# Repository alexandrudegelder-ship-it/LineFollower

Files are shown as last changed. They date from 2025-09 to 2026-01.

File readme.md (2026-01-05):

# LineFollower the best one yet !

Are you here to build a line follower ? Do you think you got what it takes to break the speed record of 0.97 m/s ? Then you have come to the right one ! 
* **Disclaimer 1: Make sure that you have enough funding, since the costs including the delivery charges of building this linefollower can be expensive in JLCPCB and Aliexpress. The calculations that I have done in the bills of materials are for the students that DON'T HAVE ANY components AT ALL. Best way to lower the costs is by forming a group of 5 people, so each of the students can have a linefollower. Also, I bought most of the components at a time when there were good deals. If possible, buy in bulk for components you buy on Aliexpress.**

* **Disclaimer 2: Please note that my electrical schematics still contain various errors. I intentionally left the errors in the documentation to ensure that working on this project isn't just a simple matter of copy-pasting. You really need to think critically about what you are doing. So, if you're planning to replicate this, I want to warn you: be careful, because 'there is more than meets the eye.'. 😜**

# Mijn Robot Project

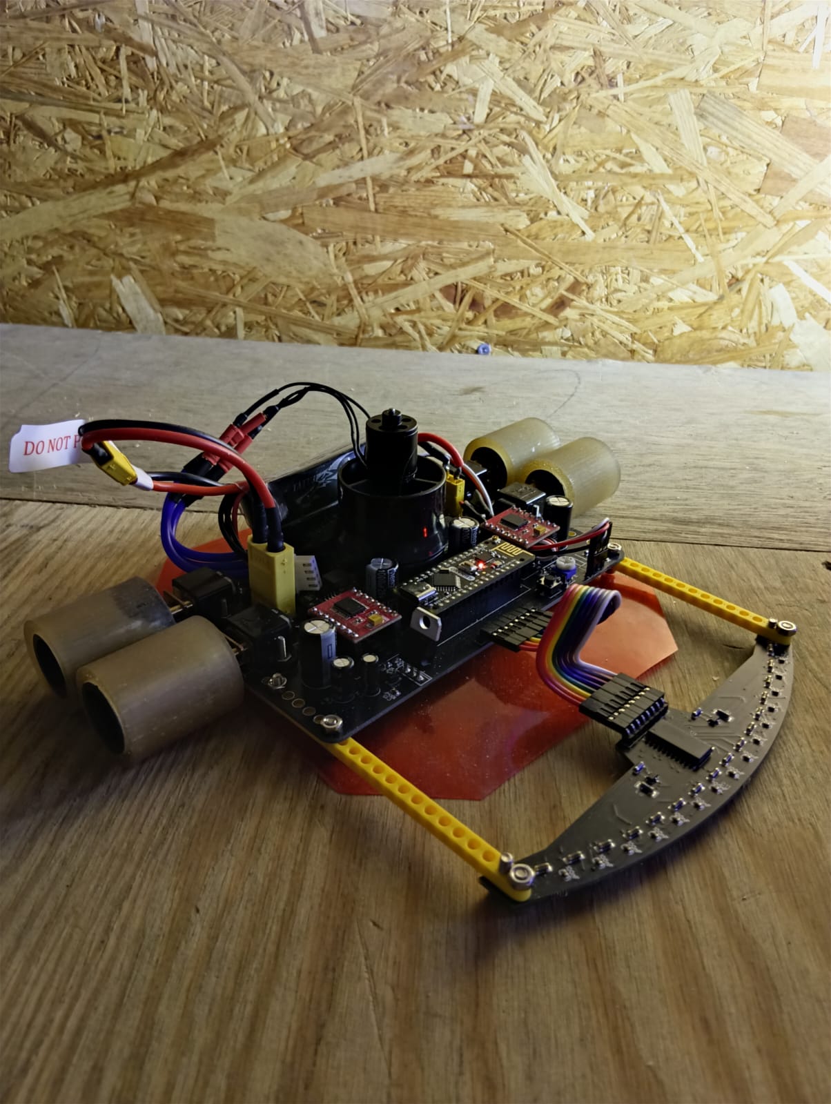
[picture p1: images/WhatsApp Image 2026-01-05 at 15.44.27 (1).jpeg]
De afgebouwde robot


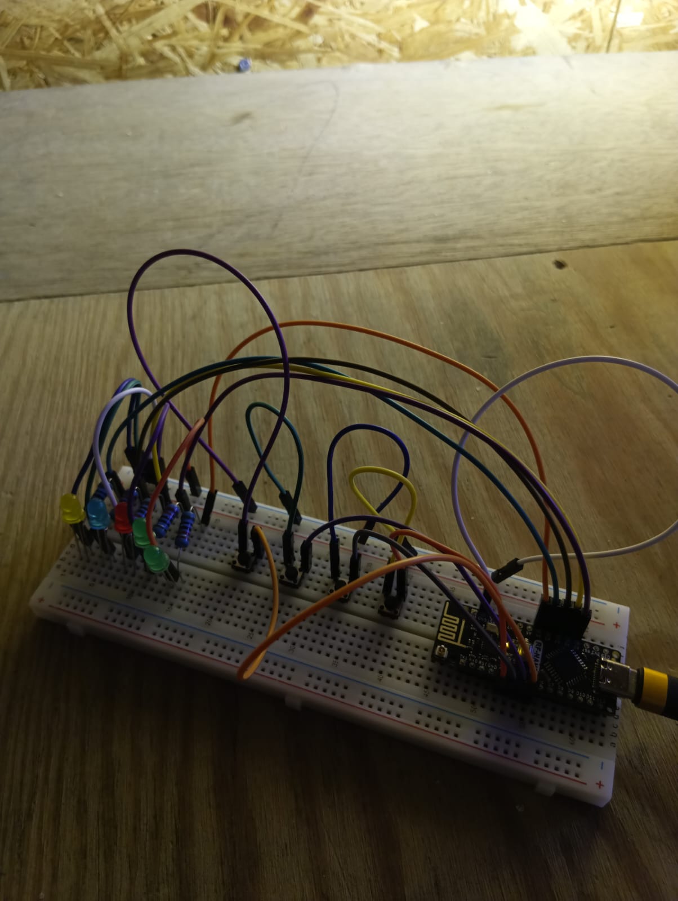
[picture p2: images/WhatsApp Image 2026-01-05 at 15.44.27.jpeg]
Breadboard testopstelling


## Specifications

* **Microcontroller:** 2x Arduino RF-Nano V3.0
* **Motors:** 2 (4x) motors GA12-N20 Motor 6V 2000 RPM (1:10)
* **H-bridge:** 2x TB6612FNG
* **Sensors:** 16x QRE1113 (Line sensor array)
* **Batteries:** 11.1V 450 mAh 3S 75C 5Wh battery
* **Wireless communication:** RF (Built-in RF in Arduino Nano)
* **Weight:** with the battery of the teacher 0.401 kg, with the one given in de BOM template 0.312 kg 
* **Speed:** Highest possible speed depending on the course (~ 0.91m/s)
* **Disclaimer:** This is currently the highest speed yet without the ventilator and POT value is 160. Further testing is needed which I have not been able to do so because of shortage of time.

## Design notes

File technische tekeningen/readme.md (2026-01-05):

# PCB ontwerp: Lineaire sensor en PCB board linefollower

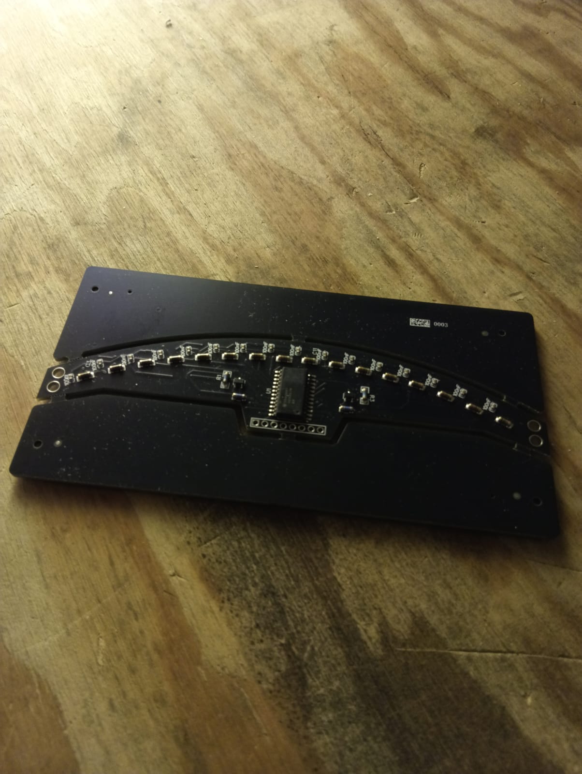
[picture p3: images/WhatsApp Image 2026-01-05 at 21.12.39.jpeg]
PCB ontwerp Lineaire sensor


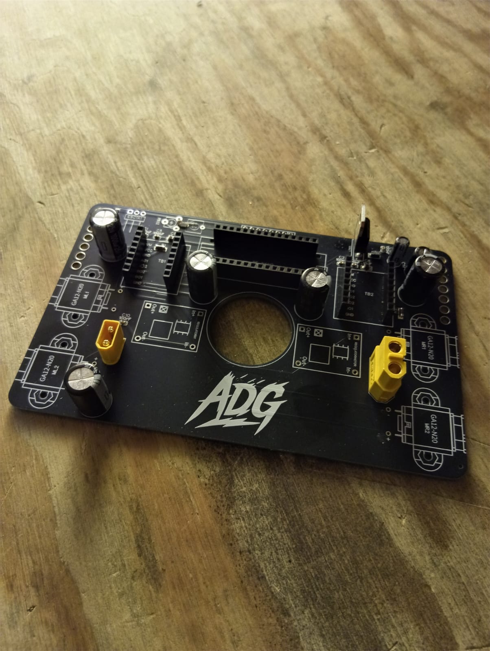
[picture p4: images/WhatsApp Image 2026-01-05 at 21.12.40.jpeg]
PCB board linefollower


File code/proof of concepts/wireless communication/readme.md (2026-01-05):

# draadloze communicatie proof of concept

# Technische Analyse: Arduino RF Nano V3.0 & Communicatie-architectuur

De **Arduino RF Nano V3.0** is een hybride microcontroller die een ATmega328P (de klassieke Nano) integreert met een **nRF24L01+** 2.4GHz transceiver op één enkele PCB. Deze integratie vereist een slimme toewijzing van pinnen om conflicten tussen interne radiofuncties en externe datacommunicatie te voorkomen.

## 1. Interne Radio-interface (SPI)

De interne nRF24L01+ chip communiceert met de processor via de **SPI-bus**. In het ontwerp van de RF Nano zijn de volgende pinnen intern vast verbonden (hard-wired):

* **D9 (CSN) & D10 (CE):** Deze pinnen sturen de radiochip aan.
* **D11, D12, D13:** De standaard SPI-lijnen (MOSI, MISO, SCK).

Omdat deze pinnen essentieel zijn voor de draadloze werking, mogen ze niet voor andere kritieke taken in het schema worden gebruikt.

## 2. Externe Communicatie via D7 en D8

Voor de bedrade communicatie tussen de bedieningsunit en de sensormodule is er specifiek gekozen voor pinnen **D7** en **D8**.

### Waarom D7 en D8?

In jouw gecorrigeerde schema fungeren deze pinnen als een **dedicated communicatiebus**.

1. **Isolatie van de Radio:** Door D7 en D8 te gebruiken, blijft de interne radio (op D9/D10) volledig ongestoord.
2. **Signaalintegriteit:** In de definitieve versie van het schema zijn de LEDs van deze pinnen verwijderd. Dit is cruciaal; een LED werkt als een ballast die de digitale flank (de overgang tussen 0V en 5V) vertraagt of vervormt, wat bij hogere baudrates tot corruptie van data leidt.
3. **Software Emulatie:** Deze pinnen zijn ideaal voor protocollen zoals *SoftwareSerial*, waarbij we een seriële poort simuleren zonder de hardwarematige USB-communicatie (D0/D1) te belasten.

## 3. Systeemintegratie & Dataflow

De kracht van jouw ontwerp ligt in de taakverdeling van de pinnen:

* **Real-time Inputs (D2/D3):** Gebruik van **Hardware Interrupts** voor de Start/Stop-knoppen. De processor stopt onmiddellijk met zijn huidige taak om deze signalen te verwerken.
* **Datatransport (D7/D8):** Zodra een interrupt wordt gedetecteerd, wordt er een datapakket via de bus op D7/D8 verzonden naar de rest van het systeem.
* **Visuele Feedback (A0-A4):** Door de LEDs naar analoge pinnen te verplaatsen, blijven de snelle digitale lijnen (zoals D7/D8) vrij van elektrische ruis.

### Samenvatting Pinbezetting

| Groep | Pinnen | Functie |
| --- | --- | --- |
| **Interrupts** | D2, D3 | Real-time Start/Stop detectie |
| **Communicatie** | **D7, D8** | Schone data-interface (bedraad) |
| **Interne RF** | D9 t/m D13 | Draadloze 2.4GHz verbinding |
| **Feedback** | A0 t/m A4 | Statusindicatie (LEDs) |

Deze opbouw garandeert een robuust systeem waarbij draadloze signalen, bedrade data en fysieke knoppen elkaar niet in de weg zitten.

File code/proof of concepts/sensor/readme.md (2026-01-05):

# Sensoren proof of concept

# Lineaire Sensor Module (PCB-ontwerp)

Dit onderdeel van het project demonstreert de onafhankelijke uitlezing van meerdere sensoren via een analoge multiplexer, waarbij de focus ligt op een maximaal dynamisch bereik en minimale software-overhead.

# 1. Hardware-architectuur

De module is opgebouwd rond de **CD74HC4067**, een 16-kanaals analoge multiplexer/demultiplexer. Hiermee kunnen tot 16 individuele "KATI"-sensoren worden uitgelezen via slechts één analoge ingang op de microcontroller.

### Onafhankelijke Uitlezing (6 Sensoren)

Hoewel de PCB 16 kanalen ondersteunt, is het systeem ontworpen om aan te tonen dat minimaal 6 sensoren volledig onafhankelijk van elkaar functioneren.

* **Multiplexing:** Door de adres-pinnen (S0 t/m S3) aan te sturen, wordt fysiek slechts één sensorpad tegelijk verbonden met de gemeenschappelijke `SIG`-lijn. Dit elimineert overspraak (cross-talk) tussen de sensoren.
* **Signaalconditionering:** Elke sensor is opgenomen in een spanningsdeler-netwerk met een precisieweerstand van **10kΩ (R21-R36)** en een **100nF condensator (C2-C17)** voor ruisonderdrukking.

# 2. Optimalisatie van het AD-Bereik

Om de 10-bit resolutie (0-1023) van de Arduino ADC optimaal te benutten, is de hardware als volgt afgestemd:

* **Spanningsbereik:** De sensoren werken op een **5V VCC**. De weerstandswaarden in de spanningsdeler zijn zo gekozen dat de spanningszwaai bij variatie van de lineaire sensor het volledige bereik tussen 0V en 5V nadert.
* **Resolutie:** Hierdoor wordt elke stap van de ADC (ongeveer 4.88mV per eenheid) effectief gebruikt, wat resulteert in een hoge precisie zonder dat er softwarematige versterking nodig is.

# 3. Minimale Software-implementatie

De software is bewust minimalistisch gehouden om de pure hardware-werking aan te tonen, zonder complexe bewerkingen zoals kalibratie of interpolatie.

### Logica:

1. **Adressering:** De microcontroller stuurt een 4-bits binair getal naar pinnen S0-S3 om de gewenste sensor (kanaal 0 t/m 5) te selecteren.
2. **Data-acquisitie:** Er wordt direct een `analogRead()` uitgevoerd op de `SIG`-lijn.
3. **Output:** De ruwe ADC-waarde wordt onmiddellijk doorgestuurd, wat bewijst dat de data direct en onbewerkt van de specifieke PCB-locatie afkomstig is.

# 4. Pinbezetting (Samenvatting)

| Component | Pin Type | Verbinding |
| --- | --- | --- |
| **Multiplexer SIG** | Analoog Input | Arduino A0 |
| **Adres S0 - S3** | Digitaal Output | Arduino D-pinnen |
| **VCC** | Voeding | 5V |
| **KATI 1-6** | Sensor Inputs | Kanalen C0 - C5 |

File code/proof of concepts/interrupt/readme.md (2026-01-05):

# start/stop interrupt proof of concept

### Projectanalyse: Start/Stop-bediening met Hardware Interrupts

Dit systeem is ontworpen om de correcte werking van een start/stop-functionaliteit aan te tonen via real-time hardware interrupts, waarbij de communicatie via een specifieke bus verloopt.

### 1. De Centrale Verwerking (Arduino RF-NANO)
De **Arduino RF-NANO** vormt het hart van de bediening.
* **Voeding:** Het systeem wordt stabiel gevoed via de **VIN-pin met 9V**.
* **Interne Logica:** De Nano zet dit intern om naar 5V voor de sensoren en knoppen.
* **RF-Gereserveerd:** De pinnen D9 en D10 zijn gereserveerd voor de ingebouwde radio-module.

### 2. Hardware Interrupt Configuratie (Minimale Hardware)
Om een onmiddellijke reactie op gebruikersinvoer te garanderen zonder de hoofdloop te vertragen, wordt gebruikgemaakt van hardware interrupts op de daarvoor bestemde pinnen.
* **START-knop (Pin D2):** Verbonden met een externe **10kΩ pull-up weerstand (R1)** naar 5V+. Dit houdt het signaal "HIGH" tot de knop wordt ingedrukt.
* **STOP-knop (Pin D3):** Eveneens verbonden met een **10kΩ pull-up weerstand (R2)**.
* **Werking:** De pinnen D2 en D3 zijn de enige pinnen op de Nano die hardware interrupts ondersteunen. Door de pull-up configuratie reageert de software op een `FALLING` edge (de overgang van 5V naar 0V bij indrukken).

### 3. Communicatie-interface (D7 en D8)
In het gecorrigeerde schema zijn pinnen **D7** en **D8** volledig gereserveerd voor datacommunicatie.
* **Vrije Lijnen:** Er zijn geen LEDs of weerstanden meer direct op deze pinnen aangesloten, wat essentieel is om signaalruis en spanningsval te voorkomen tijdens dataoverdracht.
* **Protocol:** Deze pinnen zijn nu beschikbaar voor protocollen zoals SoftwareSerial naar externe randapparatuur.

### 4. Visuele Feedback (HMI)

De indicatie-LEDs zijn verplaatst naar de analoge pinnen om de digitale pinnen vrij te maken. Elke LED is voorzien van een **220Ω voorschakelweerstand** ter bescherming.

| Indicator | Pin | Functie |
| --- | --- |---|
| **START_LED** | A0 | Bevestiging van actieve status |
| **STOP_LED** | A1 | Bevestiging van stop-commando |
| **KALIBREREN** | A2 | Status van sensor-instellingen |
| **ERROR** | A3 | Foutmelding indicatie |
| **RESET** | A4 | Bevestiging van systeem-reset |

### Technische Samenvatting

Door de **START/STOP** op **D2/D3** te plaatsen en de **communicatie** op **D7/D8**, voldoet de hardware aan de eis van "minimale hardware en software" voor een betrouwbaar, interrupt-gestuurd systeem.

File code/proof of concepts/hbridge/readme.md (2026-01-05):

# H-Bridge proof of concept

Je schema ziet er goed doordacht uit! Het gebruik van een **TB6612FNG** in combinatie met een **MP1584EN** regulator is een slimme keuze voor een robotica-project, vooral vanwege de efficiëntie.

Hier is een uitleg van hoe jouw specifieke configuratie werkt en waarom deze opbouw technisch goed in elkaar zit:

### 1. De Voedingslijn: Van Lipo naar 6V

In je tweede schema (Zie pdf schema) zie ik dat je een **11.1V bron** (waarschijnlijk een 3S LiPo batterij) via een XT60-connector aansluit op de **MP1584EN** (de "Regulator Motor").

* **De MP1584EN:** Dit is een *Step-Down (Buck) converter*. Hij zet de 11.1V efficiënt om naar **6V**. Het grote voordeel hiervan is dat je motoren een constante spanning krijgen, zelfs als de batterijspanning langzaam zakt tijdens het rijden.
* **Condensator C9 (1000uF):** Deze grote condensator aan de uitgang is essentieel. Hij vangt de "klappen" op wanneer de motoren plotseling veel stroom trekken (bijvoorbeeld bij het wegrijden), waardoor je systeem stabiel blijft en niet reset.

### 2. De TB6612FNG Dubbele H-Brug

In de schema (zie pdf) zien we de verbindingen naar de motor driver:

* **VM (Pin 1):** Deze krijgt de **6V** van je regulator. Dit is de krachtstroom die rechtstreeks naar de motoren gaat.
* **VCC (Pin 2):** Deze is verbonden met de **5V** van je Arduino. Dit voedt de interne logica van de chip. Het scheiden van VM (motoren) en VCC (logica) is cruciaal om ruis van de motoren weg te houden bij je microcontroller.
* **STBY (Pin 12):** Ik zie dat je deze via een **10kΩ weerstand (R1)** aan de 5V hebt gelegd. Dit is erg slim; het zorgt ervoor dat de driver altijd "aan" staat (niet in standby-modus) tenzij je hem handmatig laag maakt via je Arduino.

### 3. Aansluiting op de Arduino RF V3.0

De signalen die van je Arduino komen, bepalen wat de motoren doen:

* **AIN1/AIN2 & BIN1/BIN2:** Deze bepalen de **richting** van de motoren (bijv. Pin D4 en D5 voor Motor A).
* **PWMA & PWMB:** Deze zijn verbonden met PWM-pinnen (D3 en D10). Hiermee regel je de **snelheid** door de 6V pulsmatig aan te bieden.

### Waarom dit een goede setup is:

1. **Geen Oververhitting:** Omdat de TB6612FNG MOSFET's gebruikt, verlies je minder spanning dan bij een oude L298N. De 6V die je erin stopt, komt ook bijna volledig bij je motoren aan.
2. **Stroombeveiliging:** De MP1584EN kan tot 3A leveren, wat ruim voldoende is voor de meeste kleine motoren die je met deze H-brug aanstuurt (die meestal rond de 1.2A continu vragen).
3. **Ontkoppeling:** Je hebt zowel bij de 6V (C1, C3) als bij de 5V (C5, C6) condensatoren geplaatst. Dit voorkomt dat elektrische ruis van de motoren je Arduino in de war brengt.

**Tip:** Zorg dat de GND van de MP1584EN en de GND van de Arduino goed met elkaar verbonden zijn (Common Ground), anders kunnen de stuursignalen niet correct worden geïnterpreteerd door de H-brug.

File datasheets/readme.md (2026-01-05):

datasheets of the components used in this project
|Name|Datasheet|
|-----|---|
|MP1584EN datasheet| https://www.alldatasheet.com/datasheet-pdf/pdf/551593/MPS/MP1584EN.html|
|X7R|https://www.lcsc.com/datasheet/C127833.pdf|
|Alu Elco 1000 uF| https://www.lcsc.com/datasheet/C10750.pdf|
|Alu Elco 47uF|https://www.lcsc.com/datasheet/C22320.pdf|
|Keramische Condensator 10 uF|https://www.lcsc.com/datasheet/C527225.pdf|
|Keramische condensator 100 nF|https://www.lcsc.com/datasheet/C127833.pdf|
|Condensator 330 nF|https://www.lcsc.com/datasheet/C1953299.pdf|
|Weerstand 10kΩ|ttps://www.lcsc.com/datasheet/C2083262.pdf|
|Weerstand 220Ω|https://www.lcsc.com/datasheet/C104115.pdf|
|Weerstand 100kΩ|https://www.lcsc.com/datasheet/C489425.pdf|
|TI CD74HC4067M96|https://www.lcsc.com/datasheet/C496123.pdf|
|AO3400A MOSFET|https://www.lcsc.com/datasheet/C5224194.pdf|

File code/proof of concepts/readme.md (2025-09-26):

# Proof of Concepts

Een proof of concept is een combinatie van minimale hard- en software om eenvoudig aan te tonen dat iets werkt.  
Proof of concepts kunnen enerzijds als eerste poging dienen om een bepaald onderdeel van het project werkend te krijgen. Anderzijds kunnen ze tijdens het debuggen van het finale project dienen als test om eventuele hardware problemen te elimineren bij onduidelijke problemen.
<br />  
<br />
Een proof of concept bestaat uit
* een elektronisch schema (indien van toepassing)
* minimale code om de voorop gestelde zaken te demonstreren
* minimale uitleg / aandachtspunten
<br />
De elektronische schakelingen van de proof of concepts komen bij voorkeur overeen met deze van de uiteindelijke linefollower, zodat de code zonder aanpassingen op het finale project kan draaien.

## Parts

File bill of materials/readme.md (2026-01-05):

## bill of materials
<br />

|volgnummer|naam|omschrijving|nieuw/recup|kostprijs/stuk|aantal|subtotaal|Link|
|---|----|---|---|---|---|---|---|
| 1|  RF-Nano Nano V3.0  | Micro USB Board ATmega328P QFN32 5V 16M CH340 Integreren NRF24L01 + 2.4G wireless | Recup | €3.40 | 2 | €3.40  | [Aliexpress](https://nl.aliexpress.com/item/1005010571745012.html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)|
| 2| EDF 30 mm  | QX-Motor 30 MM EDF QF1611  7000 kV | New | €9.53 | 1 | €9.53  | [Aliexpress](https://nl.aliexpress.com/item/1005006079992481.html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)|
| 3|  ESC20A  | Originele Hobbywing Skywalker 20A V2 | New | €7.35 | 1 | €7.35  | [Aliexpress](https://nl.aliexpress.com/item/1005009269823714.html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)|
| 4|  Motors  | GA12-N20 Motor 6V RPM2000 Ratio 1:10 with brackets | New | €1.23 | 4 | €4.92 | [Aliexpress](https://nl.aliexpress.com/item/1005008344939451.html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)|
| 5|  Batterij  | 3S 11.1V 450mAh 75C LiPo Batterij | New | €4.03 | 1 | €4.03  | [Aliexpress](https://nl.aliexpress.com/item/1005009457370512.html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,scm-url:1007.40050.354490.0,pvid:48ccec8e-c034-40f0-8a77-22ae55b5d4ce,tpp_buckets:668%232846%238108%231977&pdp_ext_f=%7B%22order%22%3A%2213%22%2C%22spu_best_type%22%3A%22order%22%2C%22eval%22%3A%221%22%2C%22sceneId%22%3A%2230050%22%2C%22fromPage%22%3A%22recommend%22%7D&pdp_npi=6%40dis%21EUR%214.91%214.03%21%21%2139.12%2132.08%21%40211b816617676301443365037e6184%2112000049162296851%21rec%21BE%214376562053%21X%211%210%21n_tag%3A-29919%3Bd%3A8b3f2ab7%3Bm03_new_user%3A-29895&utparam-url=scene%3ApcDetailBottomMoreOtherSeller%7Cquery_from%3A%7Cx_object_id%3A1005009457370512%7C_p_origin_prod%3A)|
| 6| Headers male  | 2.54 mm x 8 pin headers male | New | €1.26 | 1 | €1.26  | [Aliexpress](https://nl.aliexpress.com/item/32963604292.html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)|
| 7|  Drukknop  | 6X6X5mm Tweepotige drukknop | New | €0.01 | 20 | €0.37  | [Aliexpress](https://nl.aliexpress.com/item/1005006053036759.html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)|
| 8| ESC20A  | Originele Hobbywing Skywalker 20A V2 | New | €7.35 | 1 | €7.35  | [Aliexpress](https://nl.aliexpress.com/item/1005009269823714.html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)|
| 9|  Dupont connector  | 2.54MM Pitch Dupont female to female  8P | New | €5.40 | 1 | €5.40  | [Aliexpress](https://nl.aliexpress.com/item/1005007987982921.html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)|
| 10|  Drivers  | TB6612 Dual Motor Driver 1A TB6612FNG | New | €1.33 | 2 | €2.65  | [Aliexpress](https://nl.aliexpress.com/item/1005005973846875.html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)|
| 11|  Potentiometer  | 65PCS Trimmer Potentiometer RM065 | New | €0.03 | 65 | €2.28  | [Aliexpress](https://nl.aliexpress.com/item/1005009003739553.html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)|
| 12|  Buck (step-down)convertor  | Mini DC-DC Verstelbare Step-down Buck Converter 3A MP1584 | Recup | €1.50 | 2 | €3.00  | [TinyTronics](https://www.tinytronics.nl/nl/power/spanningsconverters/buck-(step-down)-converters/mini-dc-dc-verstelbare-step-down-buck-converter-1a-mp1584)|
| 13|  Female Header  | 2.54mm 1 15P Brass -40℃~+105℃ 1x15P Top 1A Square Hole | New | €0.22 | 2 | €0.44  | [LCSC](https://www.lcsc.com/product-detail/C124408.html?s_z=n_C124408)|
| 14|  Female Header| Female Header 8 Position 2.54mm Pitch Single Row Through Hole | New | €0.07 | 4 | €0.28  | [LCSC](https://www.lcsc.com/product-detail/C27438.html?s_z=n_C27438)|
| 15|  Condensator  | 1000uF 25V Aluminum Electrolytic Capacitors Through Hole,D10xL17mm 2000hrs@105℃ | New | €0.06 | 2 | €0.12  | [LCSC](https://www.lcsc.com/product-detail/C10750.html?s_z=n_C10750)|
| 16|  Condensator  | 10uF ±10% 6.3V Ceramic Capacitor X7R 0805 | New | €0.03 | 2 | €0.06  | [LCSC](https://www.lcsc.com/product-detail/C527225.html?s_z=n_C527225)|
| 17|  Condensator  | 1000uF 25V Aluminum Electrolytic Capacitors Through Hole,D10xL17mm 2000hrs@105℃ | New | €0.06 | 2 | €0.12  | [LCSC](https://www.lcsc.com/product-detail/C10750.html?s_z=n_C10750)|
| 18|  Condensator  | CAP TANT 330nF ±10% 35V 1206 | New | €0.11 | 1 | €0.11 | [LCSC](https://www.lcsc.com/product-detail/C1953299.html?s_z=n_C1953299)|
| 19|  Condensator  | 47uF 16V Aluminum Electrolytic Capacitors Through Hole,D5xL11mm 1000hrs@105℃ | New | €0,64 | 1 | €0,64  | [LCSC](https://www.lcsc.com/product-detail/C22320.html?s_z=n_C22320)|
| 20|  Condensator  | 100nF ±10% 50V Ceramic Capacitor X7R 0603 | Recup | €0.01 | 23  | €0.23  | [LCSC](https://www.lcsc.com/product-detail/C127833.html?s_z=n_C127833)|
| 21|  Condensator  | 100uF 25V ±20% 159mA@120Hz Through Hole,D6.3xL11mm Aluminum Electrolytic Capacitors RoHS | New | €0.01 | 1 | €0.01  | [LCSC](https://www.lcsc.com/product-detail/C49304911.html?s_z=n_C49304911)|
| 22|  Regulator  | TO-220-3L Plastic-Encapsulate Voltage Regulators | New | €0.18 | 1  | €0.18  | [LCSC](https://www.lcsc.com/product-detail/C25503858.html?s_z=n_C25503858)|
| 23|  Weerstand  | 10kΩ ±5% 100mW 0603 Thick Film Resistor | New | €0.01 | 20 | €0.2 | [LCSC](https://www.lcsc.com/product-detail/C15401.html?s_z=n_C15401)|
| 24|  Weerstand  | RES 220Ω ±1% 250mW MELF-0204 | New | €0.01 | 17 | €0.17  | [LCSC](https://www.lcsc.com/product-detail/C2078243.html?s_z=n_C2078243)|
| 25| XT60  | Banana and Tip Connector Adapters RoHS | New | €0.23 | 1 | €0.23  | [LCSC](https://www.lcsc.com/product-detail/C19268038.html?s_z=n_C19268038)|
| 26|  XT30  | Banana and Tip Connector Adapters | New | €0.22 | 1 | €0.22  | [LCSC](https://www.lcsc.com/product-detail/C99101.html?s_z=n_XT30)|
| 27|  CD74HC4067M96  | High-Speed CMOS Logic 16-Channel Analog Multiplexer/Demultiplexer | New | €0.58 | 1 | €0.58  | [LCSC](https://www.lcsc.com/product-detail/C496123.html?s_z=n_C496123)|
| 28|  MOSFET  | MOSFET N-CH 30V 5.8A SOT23-3L | New | €0.02 | 2 | €0.04  | [LCSC](https://www.lcsc.com/product-detail/C5224194.html?s_z=n_C5224194)|
| 29|  Lineaire sensor  | QRE1113GR Miniature Reflective Object Sensor | New | €0.47 | 16 | €7.52  | [LCSC](https://www.lcsc.com/product-detail/C232862.html?s_z=n_C232862)|
| 30|  Weerstand  | RES 100Ω ±1% 250mW MELF-0204 | New | €0,02 | 2 | €0.05  | [LCSC](https://www.lcsc.com/product-detail/C2074944.html?s_z=n_C2074944)|
| 31|  Weerstand  | RES 100kΩ ±1% 250mW MELF | New | €0.02 | 2 | €0.04  | [LCSC](https://www.lcsc.com/product-detail/C489425.html?s_z=n_C489425)|
|Belanrijk| | Zonder vervoerskosten bij Aliexpress, TinyTronics en LCSC | | € 45,57 | | €62,78  ||

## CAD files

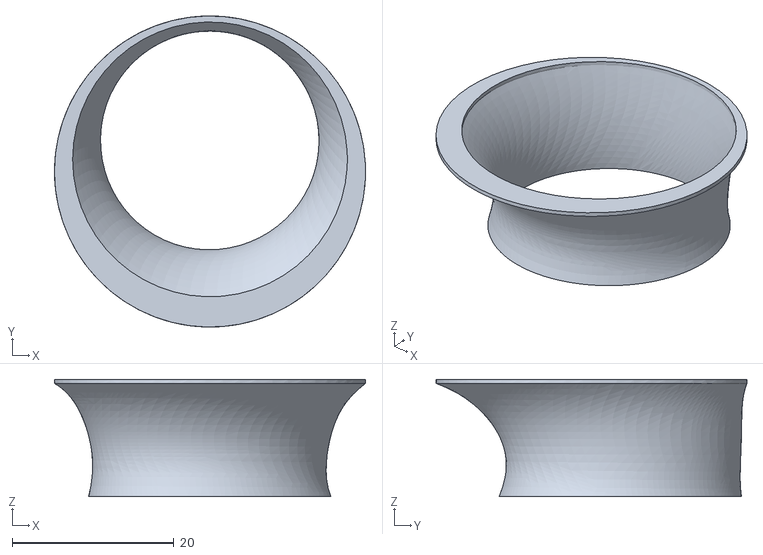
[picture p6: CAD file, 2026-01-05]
technische tekeningen/mechanisch/Trechter.STL
38.5 x 38.5 x 14.5

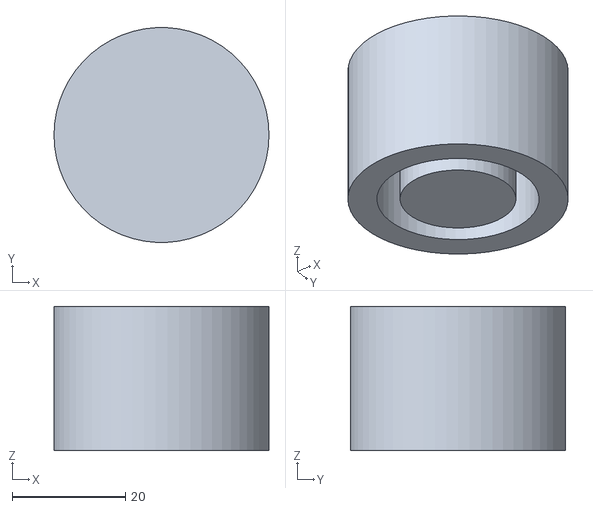
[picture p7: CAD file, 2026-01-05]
technische tekeningen/mechanisch/mal voor band.STL
38.0 x 37.9 x 25.5

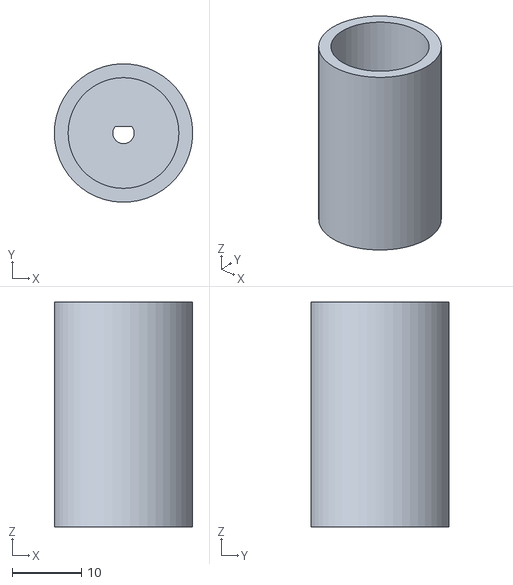
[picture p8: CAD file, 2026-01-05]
technische tekeningen/mechanisch/Wiel1.STL
20.0 x 20.0 x 32.5

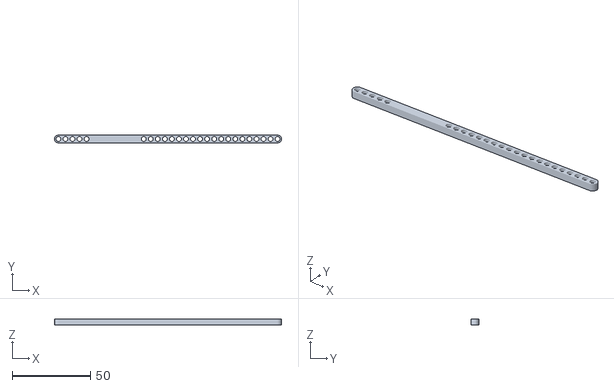
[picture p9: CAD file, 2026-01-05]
technische tekeningen/mechanisch/staaf.STL
145.0 x 5.00 x 3.70

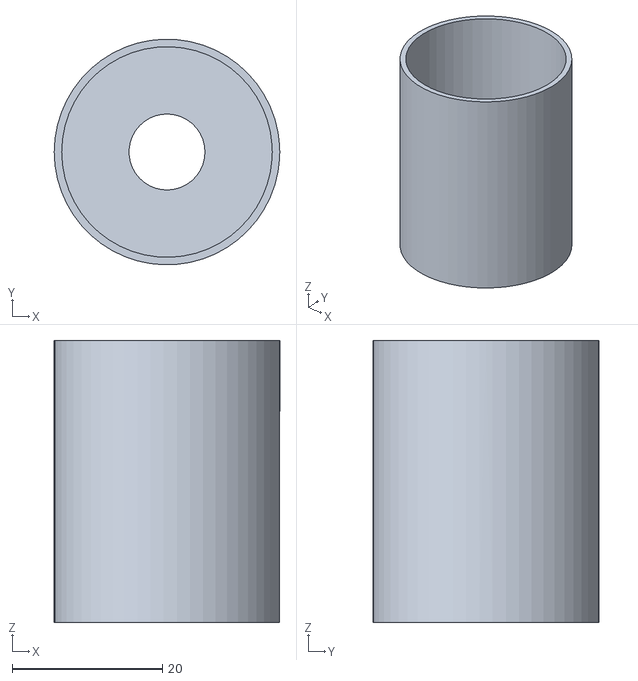
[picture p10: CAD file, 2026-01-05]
technische tekeningen/mechanisch/Mal voor wiel 2.STL
30.0 x 30.0 x 37.5

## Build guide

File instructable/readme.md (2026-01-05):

# Instructable: Linefollower Robot Assembly

Dit stappenplan beschrijft hoe je de robot bouwt met de JLCPCB-modules en de 3D-geprinte mechanische onderdelen.

### Stap 1: Bestellen van Hardware & PCB's

1. **Elektronika:** Exporteer de Gerber-bestanden en de Bill of Materials (BOM) vanuit **EasyEDA**. Bestel de PCB's bij **JLCPCB** en maak gebruik van hun SMT-assemblageservice voor de Startbediening en de Lineaire Sensor PCB.
2. **Mechaniek:** Bestel of 3D-print de volgende onderdelen op basis van de bijgevoegde STL-bestanden:
* `Wiel1.STL` & `Mal voor wiel 2.STL` (Wielen en gietmallen).
* `Trechter.STL` (onderdeel om EDF30 te ondersteunen).
* `staaf.STL` (Structurele verbindingen).

### Stap 2: Mechanische Voorbereiding

1. **Wielen:** Gebruik de 3D-geprinte mallen (`Mal voor wiel 2.STL`) om rubberen of siliconen banden te gieten rondom `Wiel1.STL` voor maximale grip.
2. **Frame:** Monteer de `staaf.STL` onderdelen op het chassis van de robot om de basisstructuur te vormen.
3. **Behuizing:** Plaats de `Trechter.STL` op de voorziene positie voor als frame ondersteuning voor de EDF30 mm.

### Stap 3: Assemblage van de Elektronica

1. **Sensormodule:** Bevestig de kant-en-klare **Lineaire Sensor PCB** aan de voorzijde van de robot, zo dicht mogelijk bij de grond.
2. **Masterbediening:** Monteer de **Startbediening PCB** op een goed bereikbare plaats aan de bovenzijde.
3. **Microcontrollers:** Plaats de twee **Arduino RF Nano V3.0** modules in de headers van de PCB's (indien niet reeds meegeleverd door JLCPCB).

### Stap 4: Bedrading

1. Verbind de motoren met de motordriver-uitgangen op de Slave-unit.
2. Sluit de batterij (bijv. 11.1V LiPo) aan op de voedingsingang van de Master/Slave.
3. Controleer de gedeelde **GND** (massa) over het gehele systeem.

### Stap 5: Compileren en Uploaden

1. **Voorbereiding:** Installeer de `RF24` bibliotheek in de Arduino IDE.
2. **Master (Bediening):** * Open de Master-code.
* Selecteer Board: **Arduino Nano** | Processor: **ATmega328P (Old Bootloader)**.
* Upload via USB naar de Master RF Nano.

3. **Slave (Robot):** * Open de Slave-code.
* Herhaal de instellingen en upload naar de Slave RF Nano aan de onderzijde van de robot.

### Stap 6: Kalibratie en Testen

1. Zet de robot op een witte ondergrond met een zwarte lijn.
2. Druk op de **START** knop op de Masterbediening. De RF-verbinding activeert de Slave.
3. Controleer via de Seriële Monitor of de **CD74HC4067 multiplexer** de sensordata correct doorgeeft (waarden tussen 0-1023).
4. Gebruik de **STOP** knop voor een onmiddellijke interrupt-gebaseerde stilstand.

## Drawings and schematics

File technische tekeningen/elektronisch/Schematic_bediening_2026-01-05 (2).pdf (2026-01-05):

Arduino | Drukknoppen

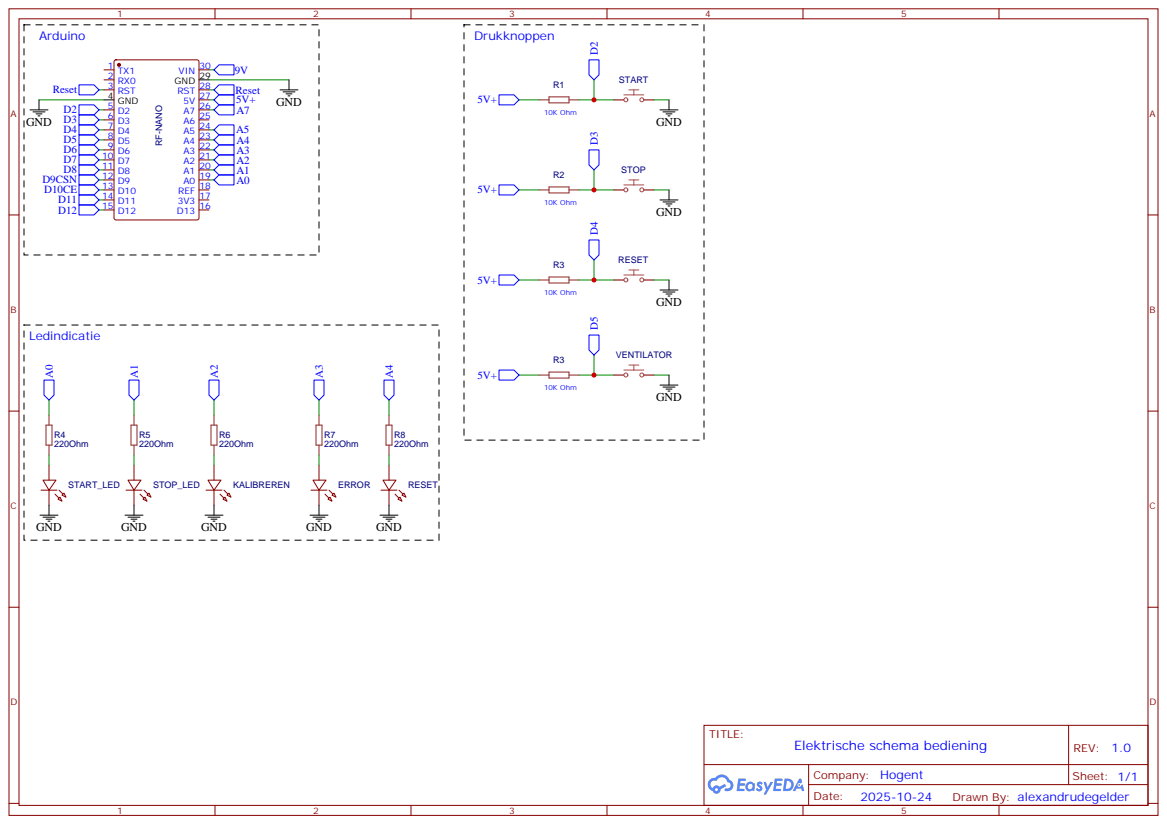
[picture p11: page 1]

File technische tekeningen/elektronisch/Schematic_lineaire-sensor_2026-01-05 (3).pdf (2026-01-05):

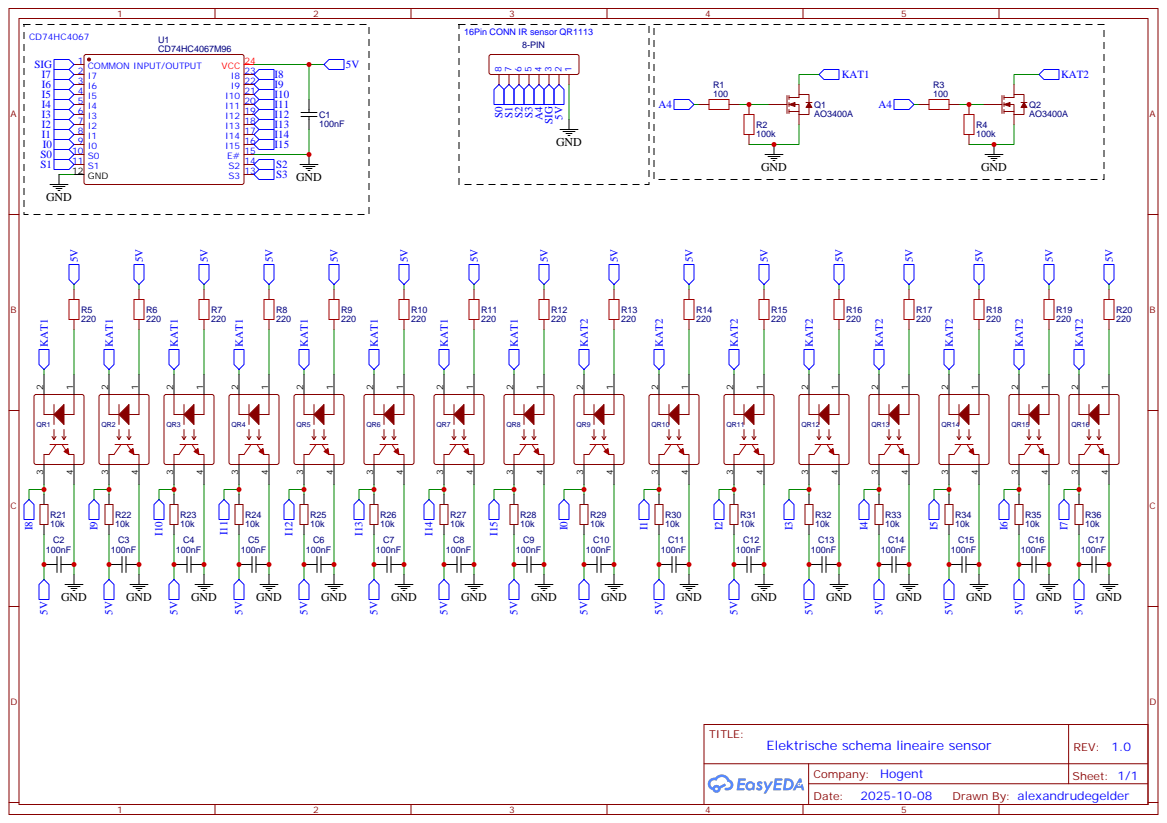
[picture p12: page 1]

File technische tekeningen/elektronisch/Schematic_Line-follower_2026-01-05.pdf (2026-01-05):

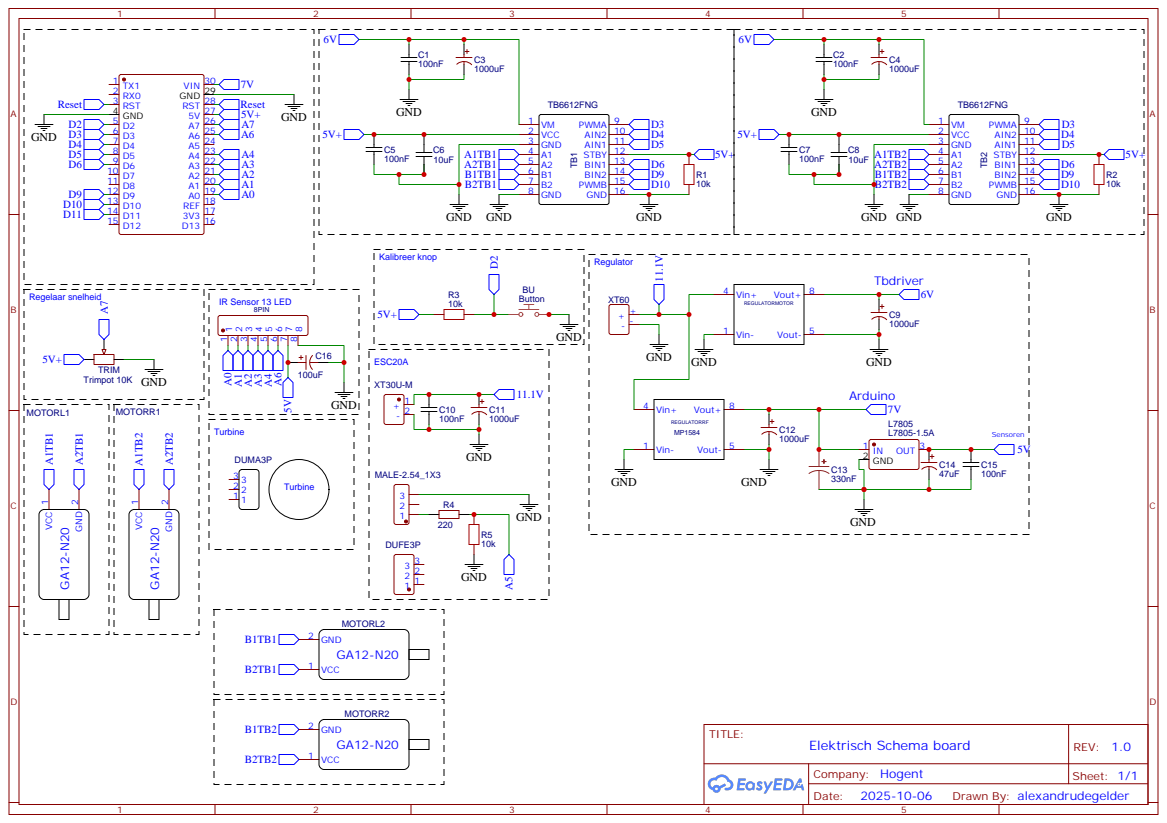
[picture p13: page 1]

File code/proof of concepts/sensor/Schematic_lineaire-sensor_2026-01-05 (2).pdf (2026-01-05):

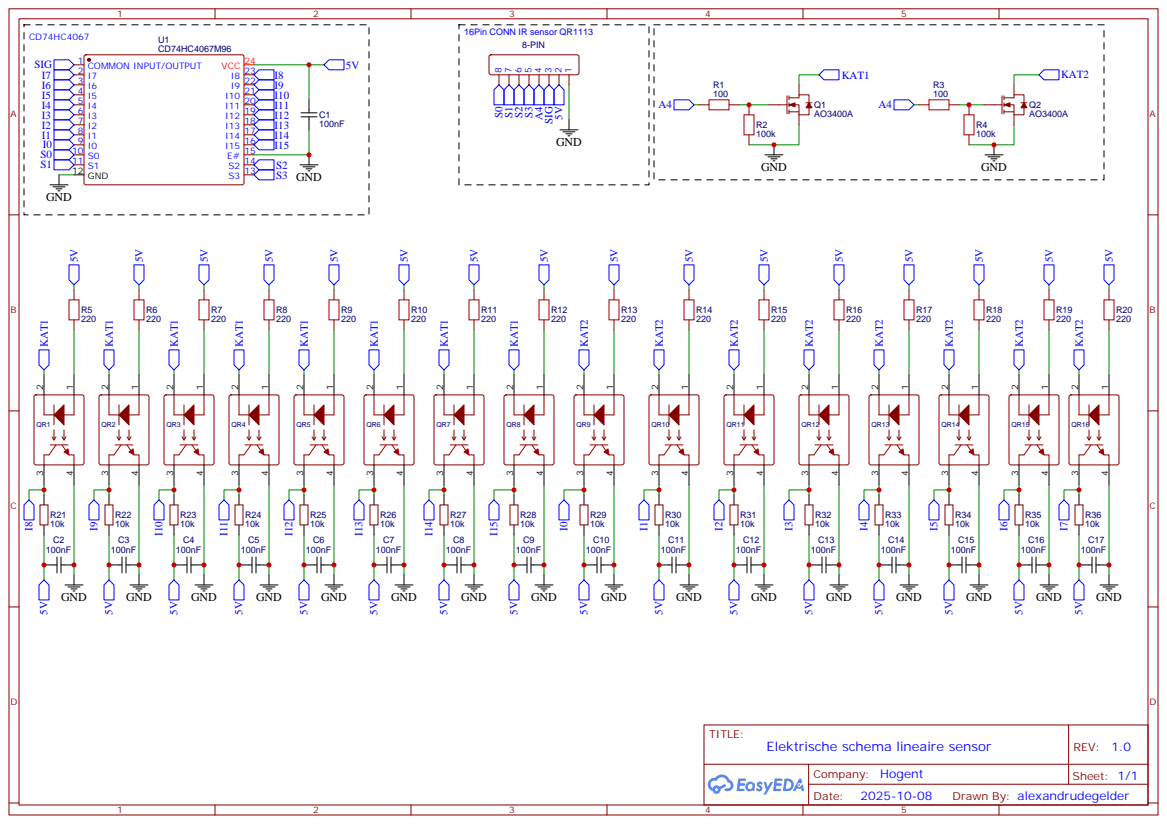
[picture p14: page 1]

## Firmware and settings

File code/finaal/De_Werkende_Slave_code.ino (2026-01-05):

#include <SPI.h>
#include <RF24.h>
#include <EEPROM.h>
#include <math.h> 

RF24 radio(7, 8);
const byte ADDR_SM[6] = "SM001";
const byte ADDR_MS[6] = "MS001";

#define MUX_S0  A0
#define MUX_S1  A1
#define MUX_S2  A2
#define MUX_S3  A3
#define SIG     A6
#define MOSFET  A4
#define BTN     2 

#define AIN1    4
#define AIN2    5
#define BIN1    6
#define BIN2    9
#define PWMA    3
#define PWMB    10

#define ESC_PIN A5
const uint16_t ESC_IDLE_US   = 1100;
const uint16_t ESC_RUN_US    = 1400;
const uint16_t ESC_PERIOD_US = 20000;

const unsigned long CYCLE_US = 8000;
static unsigned long lastCycleUs = 0;

int sensorOrder[16] = { 8,9,10,11,12,13,14,15, 0,1,2,3,4,5,6,7 };
uint16_t sensorVal[16];
uint16_t avgWhite[16];
uint16_t avgBlack[16];
float w[16];
float linePosMM = 9999.0f;
uint8_t dig[16];
uint8_t calibStep = 0;
const uint8_t  N_SAMPLES = 8;
const uint16_t SAMPLE_DELAY_MS = 10;

const float HALF_EFF = 37.4f;  
const float L_EFF    = 74.8f; 

unsigned long lastTX = 0;
const unsigned long TX_MS = 200;

static const uint32_t EEPROM_MAGIC = 0xC0A1BEEF;
struct CalData {
  uint32_t magic;
  uint16_t white[16];
  uint16_t black[16];
};

bool lastBtnRead = HIGH;
bool lastBtnStable = HIGH;
unsigned long lastDeb = 0;
const unsigned long DEB_MS = 40;

bool enginesRunning = false;
bool fanOn = false;
uint8_t motorPwm = 0;

// ---------- ESC CONTROLLER ----------
unsigned long escNextStartUs  = 0;
unsigned long escPulseStartUs = 0;
bool escHigh = false;
uint16_t escPulseUs = ESC_IDLE_US;

static inline void escUpdateNonBlocking() {
  unsigned long now = micros();
  if (!escHigh) {
    if ((long)(now - escNextStartUs) >= 0) {
      escPulseStartUs = now;
      digitalWrite(ESC_PIN, HIGH);
      escHigh = true;
    }
  } else {
    if ((unsigned long)(now - escPulseStartUs) >= escPulseUs) {
      digitalWrite(ESC_PIN, LOW);
      escHigh = false;
      escNextStartUs = escPulseStartUs + ESC_PERIOD_US;
    }
  }
}

// ---------------- COMMUNICATIE ----------------
static inline void sendText(const char* msg) {
  radio.stopListening();
  radio.write(msg, strlen(msg) + 1);
  radio.startListening();
}

static inline void sendConfirm(const char* msg) {
  for (uint8_t i = 0; i < 3; i++) {
    sendText(msg);
    delay(30); 
  }
}

static inline void sendPosToMaster() {
  char posStr[10];
  dtostrf(linePosMM, 6, 2, posStr);
  char msg[16];
  snprintf(msg, sizeof(msg), "M%s", posStr);
  sendText(msg);
}

// ---------------- MOTOREN ----------------
static inline void setMotorSigned(int left, int right) {
  if (left >= 0) { digitalWrite(AIN1, LOW); digitalWrite(AIN2, HIGH); }
  else { digitalWrite(AIN1, HIGH); digitalWrite(AIN2, LOW); left = -left; }
  if (right >= 0) { digitalWrite(BIN1, HIGH); digitalWrite(BIN2, LOW); }
  else { digitalWrite(BIN1, LOW); digitalWrite(BIN2, HIGH); right = -right; }
  analogWrite(PWMA, constrain(left, 0, 255));
  analogWrite(PWMB, constrain(right, 0, 255));
}

static inline void enginesStart() {
  enginesRunning = true;
  sendConfirm("EnginesRunning");
}

static inline void enginesStop() {
  enginesRunning = false;
  setMotorSigned(0, 0);
  sendConfirm("EnginesStopped");
}

// ---------------- SENSORIEK ----------------
static inline void updateSensors() {
  for (int i = 0; i < 16; i++) {
    if (i <= 1 || i >= 14) { sensorVal[i] = 0; continue; }
    int ch = sensorOrder[i];
    digitalWrite(MUX_S0, ch & 1); digitalWrite(MUX_S1, ch & 2);
    digitalWrite(MUX_S2, ch & 4); digitalWrite(MUX_S3, ch & 8);
    sensorVal[i] = (uint16_t)analogRead(SIG);
  }
}

static inline void captureAverage(uint16_t outAvg[16]) {
  uint32_t acc[16] = {0};
  for (uint8_t k = 0; k < N_SAMPLES; k++) {
    updateSensors();
    for (int i = 0; i < 16; i++) acc[i] += sensorVal[i];
    delay(SAMPLE_DELAY_MS);
  }
  for (int i = 0; i < 16; i++) outAvg[i] = (uint16_t)(acc[i] / N_SAMPLES);
}

static inline void computeAll() {
  if (calibStep != 2) {
    for (int i = 0; i < 16; i++) { w[i] = 0.0f; dig[i] = 0; }
    linePosMM = 9999.0f;
    return;
  }
  updateSensors();

  int activeCount = 0;
  for (int i = 2; i <= 13; i++) {
    float white = (float)avgWhite[i]; float black = (float)avgBlack[i];
    float v = (float)sensorVal[i]; float denom = black - white;
    if (denom < 5.0f) { w[i] = 0.0f; dig[i] = 0; continue; }
    w[i] = constrain((v - white) / denom, 0.0f, 1.0f);
    float thr = (white + black) * 0.5f;
    dig[i] = (v > thr) ? 1 : 0;
    if (dig[i]) activeCount++;
  }

  float sumW = 0.0f; float sumX = 0.0f;
  for (int i = 2; i <= 13; i++) {
    if (dig[i]) {
      bool hasNeighbor = false;
      if (i > 2 && dig[i-1]) hasNeighbor = true;
      if (i < 13 && dig[i+1]) hasNeighbor = true;
      if (hasNeighbor || activeCount == 1) { 
        float x = -HALF_EFF + (float)(i - 2) * (L_EFF / 11.0f);
        sumW += w[i];
        sumX += w[i] * x;
      } else {
        dig[i] = 0; 
      }
    }
  }
  if (sumW < 0.02f) linePosMM = 9999.0f;
  else linePosMM = sumX / sumW;
}

// ---------------- STUURLOGICA (AGRESSIEVE BOCHT VERSIE) ----------------
static float lastPos = 0;
static float lastKnownPos = 0;

static inline void applyLineFollowPID() {
  computeAll();
  int base = (int)motorPwm;

  if (linePosMM > 9000.0f) { 
      if (lastKnownPos > 0) setMotorSigned(base + 85, -145); 
      else                  setMotorSigned(-145, base + 85);
      return; 
  }

  float pos = linePosMM;
  float absPos = fabs(pos);
  float diff = pos - lastPos; 
  
  if (absPos < 3.0f) {
      setMotorSigned(base, base); 
      lastPos = pos;
      return;
  }

  // Basis alertheid
  float pFactor = 0.75f + (absPos * 0.015f); 
  
  float dFactor;
  if ((pos > 0 && diff < 0) || (pos < 0 && diff > 0)) {
      dFactor = 12.0f; // Sneller terugkeren naar de lijn
  } else {
      dFactor = 6.0f;  
  }

  float pTerm = pos * pFactor;
  float dTerm = diff * dFactor;
  lastPos = pos;
  lastKnownPos = pos;

  int output = (int)(pTerm + dTerm);

  // --- BOCHT HULP: Grijpt eerder en harder in ---
  int finalOutput = output;
  if (absPos > 8.0f) {
      float extra = (absPos - 8.0f) * 4.5f; 
      finalOutput += (pos > 0) ? (int)extra : -(int)extra;
  }

  int finalSteer = constrain(finalOutput, -250, 250);
  setMotorSigned(base + finalSteer, base - finalSteer);
}

// ---------------- EEPROM, SETUP & LOOP ----------------
static inline void saveCalToEEPROM() {
  CalData d; d.magic = EEPROM_MAGIC;
  for (int i = 0; i < 16; i++) { d.white[i] = avgWhite[i]; d.black[i] = avgBlack[i]; }
  EEPROM.put(0, d);
}

static inline bool loadCalFromEEPROM() {
  CalData d; EEPROM.get(0, d);
  if (d.magic != EEPROM_MAGIC) return false;
  for (int i = 0; i < 16; i++) { avgWhite[i] = d.white[i]; avgBlack[i] = d.black[i]; }
  return true;
}

void setup() {
  Serial.begin(9600);
  pinMode(BTN, INPUT_PULLUP);
  pinMode(MOSFET, OUTPUT); digitalWrite(MOSFET, HIGH);
  pinMode(MUX_S0, OUTPUT); pinMode(MUX_S1, OUTPUT);
  pinMode(MUX_S2, OUTPUT); pinMode(MUX_S3, OUTPUT);
  pinMode(AIN1, OUTPUT); pinMode(AIN2, OUTPUT);
  pinMode(BIN1, OUTPUT); pinMode(BIN2, OUTPUT);
  pinMode(PWMA, OUTPUT); pinMode(PWMB, OUTPUT);
  pinMode(ESC_PIN, OUTPUT); digitalWrite(ESC_PIN, LOW);
  escNextStartUs = micros();

  radio.begin();
  radio.setDataRate(RF24_250KBPS);
  radio.setChannel(100);
  radio.setPALevel(RF24_PA_LOW);
  radio.openReadingPipe(0, ADDR_MS);
  radio.openWritingPipe(ADDR_SM);
  radio.startListening();

  if (loadCalFromEEPROM()) calibStep = 2;
  lastCycleUs = micros();
}

void loop() {
  escUpdateNonBlocking();
  while (radio.available()) {
    char msg[32] = {0}; radio.read(msg, sizeof(msg));
    if (strcmp(msg, "StartEngines") == 0) enginesStart();
    else if (strcmp(msg, "StopEngines") == 0) { enginesStop(); fanOn = false; escPulseUs = ESC_IDLE_US; }
    else if (strcmp(msg, "VentilatorOn") == 0) { fanOn = true; escPulseUs = ESC_RUN_US; }
    else if (strcmp(msg, "VentilatorOff") == 0) { fanOn = false; escPulseUs = ESC_IDLE_US; }
  }

  bool r = digitalRead(BTN);
  if (r != lastBtnRead) { lastBtnRead = r; lastDeb = millis(); }
  if (millis() - lastDeb >= DEB_MS) {
    if (r != lastBtnStable) {
      lastBtnStable = r;
      if (lastBtnStable == LOW) {
        if (calibStep == 2) { calibStep = 0; sendConfirm("herkalibratie start"); }
        else if (calibStep == 0) { captureAverage(avgWhite); calibStep = 1; }
        else if (calibStep == 1) { captureAverage(avgBlack); saveCalToEEPROM(); calibStep = 2; }
      }
    }
  }

  unsigned long nowUs = micros();
  if (nowUs - lastCycleUs >= CYCLE_US) {
    lastCycleUs += CYCLE_US;
    motorPwm = (uint8_t)(analogRead(A7) / 4);
    if (enginesRunning) applyLineFollowPID();
  }

  if (calibStep == 2 && millis() - lastTX >= TX_MS) {
    lastTX = millis();
    computeAll();
    char bMsg[18]; bMsg[0] = 'B';
    for (int i = 0; i < 16; i++) bMsg[1 + i] = dig[i] ? '1' : '0';
    bMsg[17] = '\0';
    sendText(bMsg);
    char pMsg[16]; snprintf(pMsg, sizeof(pMsg), "P%d", (int)(motorPwm));
    sendText(pMsg);
    sendPosToMaster();
  }
}

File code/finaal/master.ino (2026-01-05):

#include <SPI.h>
#include <RF24.h>
#include <string.h>
#include <stdlib.h>

RF24 radio(7, 8);
const byte ADDR_SM[6] = "SM001";  // Slave→Master
const byte ADDR_MS[6] = "MS001";  // Master→Slave

const int LED_PIN = 6;

// === Knoppen ===
const int PIN_START = 2;   // INT0
const int PIN_STOP  = 3;   // INT1
const int PIN_RESET = 4;   // PCINT (pin change)
const unsigned long DEBOUNCE_MS = 40;

// LED modes
#define LED_OFF        0
#define LED_STEADY     1
#define LED_BLINK_1HZ  2
#define LED_BLINK_20HZ 3

int ledMode = LED_OFF;
unsigned long lastToggle = 0;
const unsigned long T1  = 500;  // 1 Hz
const unsigned long T20 = 25;   // 20 Hz

// S4 tijd-gestuurd (waterdicht)
bool s4Active = false;
unsigned long s4Start = 0;

// === knop-ISR data (volatile) ===
volatile bool isrStartRaw = false;
volatile bool isrStopRaw  = false;
volatile bool isrResetRaw = false;
volatile bool isrStartDirty = false;
volatile bool isrStopDirty  = false;
volatile bool isrResetDirty = false;

// === debounce/stable ===
bool startStable = false, startLast = false;
bool stopStable  = false, stopLast  = false;
bool resetStable = false, resetLast = false;
unsigned long tStartChange = 0, tStopChange = 0, tResetChange = 0;

void setLed(bool on){ digitalWrite(LED_PIN, on ? HIGH : LOW); }
void setLedMode(int m){
  if (m == ledMode) return;
  ledMode = m;
  lastToggle = millis();
  if (m == LED_OFF)    setLed(false);
  if (m == LED_STEADY) setLed(true);
}

void updateLed(){
  unsigned long now = millis();
  if (ledMode == LED_BLINK_1HZ  && (now - lastToggle >= T1 )) { lastToggle = now; digitalWrite(LED_PIN, !digitalRead(LED_PIN)); }
  if (ledMode == LED_BLINK_20HZ && (now - lastToggle >= T20)) { lastToggle = now; digitalWrite(LED_PIN, !digitalRead(LED_PIN)); }

  // S4: 0–3s knipper, 3–6s steady, >6s uit
  if (s4Active){
    unsigned long dt = now - s4Start;
    if (dt < 3000)      setLedMode(LED_BLINK_1HZ);
    else if (dt < 6000) setLedMode(LED_STEADY);
    else { setLedMode(LED_OFF); s4Active = false; }
  }
}

void startS4IfNeeded(){
  if (!s4Active){ s4Active = true; s4Start = millis(); setLedMode(LED_BLINK_1HZ); }
}
void stopS4(){ s4Active = false; }

// === radio TX helper (master → slave) ===
void sendToSlave(const char* tag){
  radio.stopListening();                    // kort naar TX
  radio.openWritingPipe(ADDR_MS);
  char msg[32] = {0};
  strncpy(msg, tag, sizeof(msg)-1);
  radio.write(msg, strlen(msg)+1);
  radio.startListening();                   // zo snel mogelijk terug naar RX
}

// === ISR's (active LOW) ===
void isrStart(){
  bool raw = (digitalRead(PIN_START) == LOW);
  isrStartRaw = raw; isrStartDirty = true;
}
void isrStop(){
  bool raw = (digitalRead(PIN_STOP) == LOW);
  isrStopRaw = raw; isrStopDirty = true;
}
// D4 via pin-change interrupt (PCINT2_vect)
ISR(PCINT2_vect){
  bool raw = (PIND & _BV(PD4)) == 0;   // LOW = ingedrukt
  isrResetRaw = raw; isrResetDirty = true;
}

void serviceButtons(){
  unsigned long now = millis();

  // START (D2)
  if (isrStartDirty){ isrStartDirty = false; tStartChange = now; }
  if (now - tStartChange >= DEBOUNCE_MS){
    startStable = isrStartRaw;
    bool pressed  = (!startLast && startStable);
    bool released = ( startLast && !startStable);
    if (pressed)  sendToSlave("start");
    if (released) sendToSlave("running");
    startLast = startStable;
  }

  // STOP (D3)
  if (isrStopDirty){ isrStopDirty = false; tStopChange = now; }
  if (now - tStopChange >= DEBOUNCE_MS){
    stopStable = isrStopRaw;
    bool pressed  = (!stopLast && stopStable);
    bool released = ( stopLast && !stopStable);
    if (pressed)  sendToSlave("stop");
    if (released) sendToSlave("ended");
    stopLast = stopStable;
  }

  // RESET (D4)
  if (isrResetDirty){ isrResetDirty = false; tResetChange = now; }
  if (now - tResetChange >= DEBOUNCE_MS){
    resetStable = isrResetRaw;
    bool pressed  = (!resetLast && resetStable);
    bool released = ( resetLast && !resetStable);
    if (pressed)  sendToSlave("reset");
    if (released) sendToSlave("master ready");
    resetLast = resetStable;
  }
}

// === RX (slave → master, bestaand) ===
void handleMessage(const char* msg){
  // --- S4: tijd-gestuurd, berichten enkel trigger ---
  if (!strncmp(msg, "S4|standby", 10)){ startS4IfNeeded(); return; }
  if (!strncmp(msg, "S4|kalibreren compleet", 23)){ startS4IfNeeded(); return; }

  // --- S0 reset ---
  if (!strncmp(msg, "S0|ready", 8)){ setLedMode(LED_OFF); stopS4(); return; }

  // --- S1 (wit) ---
  if (!strncmp(msg, "S1|begin", 8))                { setLedMode(LED_STEADY); stopS4(); return; }
  if (!strncmp(msg, "S1|ready", 8))                { setLedMode(LED_STEADY); return; }
  if (!strncmp(msg, "S1|standby", 10))             { setLedMode(LED_BLINK_1HZ); return; }
  if (!strncmp(msg, "S1|wit kalibreren", 17))      { setLedMode(LED_BLINK_20HZ); return; }
  if (!strncmp(msg, "S1|wit compleet", 15))        { setLedMode(LED_BLINK_1HZ); return; }

  // --- S2 ---
  if (!strncmp(msg, "S2|ready", 8))                { setLedMode(LED_BLINK_1HZ); return; }

  // --- S3 (zwart) ---
  if (!strncmp(msg, "S3|zwart kalibreren", 19))    { setLedMode(LED_BLINK_20HZ); return; }
  if (!strncmp(msg, "S3|standby", 10))             { setLedMode(LED_BLINK_1HZ); return; }
}

void setup(){
  Serial.begin(9600);

  pinMode(LED_PIN, OUTPUT);
  setLed(false);

  // knoppen (naar GND)
  pinMode(PIN_START, INPUT_PULLUP);
  pinMode(PIN_STOP,  INPUT_PULLUP);
  pinMode(PIN_RESET, INPUT_PULLUP);

  // init raw-states
  isrStartRaw = (digitalRead(PIN_START) == LOW);
  isrStopRaw  = (digitalRead(PIN_STOP)  == LOW);
  isrResetRaw = (digitalRead(PIN_RESET) == LOW);
  startLast = startStable = isrStartRaw;
  stopLast  = stopStable  = isrStopRaw;
  resetLast = resetStable = isrResetRaw;

  // externe interrupts
  attachInterrupt(digitalPinToInterrupt(PIN_START), isrStart, CHANGE);
  attachInterrupt(digitalPinToInterrupt(PIN_STOP),  isrStop,  CHANGE);

  // pin-change interrupt voor D4 (PD4 = PCINT20) → PCINT2 vector
  PCICR  |= _BV(PCIE2);     // enable PCINT[23:16]
  PCMSK2 |= _BV(PCINT20);   // enable PD4 (D4)

  // radio
  radio.begin();
  radio.setDataRate(RF24_250KBPS);
  radio.setChannel(100);
  radio.setAutoAck(true);
  radio.setRetries(3, 5);          // korter, minder TX-blokkade
  radio.setPALevel(RF24_PA_LOW);

  radio.openReadingPipe(0, ADDR_SM); // RX: SLAVE -> MASTER
  radio.openWritingPipe(ADDR_MS);    // TX: MASTER -> SLAVE
  radio.startListening();

  Serial.println("MASTER ready");
}

void loop(){
  // verwerk knoppen
  serviceButtons();

  // RX
  if (radio.available()){
    char msg[32] = {0};
    radio.read(msg, sizeof(msg));
    handleMessage(msg);
  }

  // LED
  updateLed();
}
